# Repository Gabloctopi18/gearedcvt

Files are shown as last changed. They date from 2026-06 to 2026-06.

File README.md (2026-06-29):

# Geared, Bi-directional CVT
A continously variable transmission that is fully geared and is bi-directional. I was heavily inspired by RatioZero.
Here is the link to the CAD: [https://cad.onshape.com/documents/c369754a085e1b437744081a/w/8784f23027b47ba880d55ef1/e/7f96dc46c879863ea30c1be9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](url)

Here is my project on stardance: [https://stardance.hackclub.com/projects/4431](url)



## Context
### What is a CVT? Why CVT?
A CVT (continously variable transmission) is a gearbox which allows an infinite, continuous range of gear ratios. Unlike normal gearboxes or gear switchers, which have fixed gear ratios and sharp switching between them, a CVT allows any gear ratio between it's mechanical limits (dependent on the mechanical design). For automotive industries, CVTs are used to keep engines at optimal efficiency RPM (deviations greatly reduce efficiency) and instead change speed by varying the gear ratio. However, my CVT is meant to be used in robotics: instead of compromising between speed and torque, a CVT allows both torque and speed modes in one gearbox. Robots that are used in a wide range of scenarios and load conditions benefit from it: it can choose the optimal gear ratio for each desired action.
### Why geared? Why bi-directional?
I chose to design a geared CVT mainly becaues I thought it looked really cool. Theoretically, geared CVTs are more efficient than typical belted CVTs because gears are inherently more efficient than belts. Furthermore, belted CVTs rely solely on friction, while geared CVTs rely on the mechanical interlocking of gears, redicuing manufacturing costs. One really good and popular Geared CVT design is the RatioZero. However, that gearbox is not bi-directional because it relies on one-way bearings: when you spin the input in reverse, the ouput doesn't spin. This also implies that there is no inherent braking mechanism. In many robotics applications, it is not feasible to use another actuator as a brake, and it is often necessary for the gearbox to be able to spin in both ways (think of a robotic arm or a mecanum drivetrain for example). My CVT is fully geared and bi-directional.

## How it works

Here is a brief overview of how the whole thing works. I recommend taking a look at the CAD because it's hard to explain stuff with only images.

### Rotation Splitting
The key idea for the geared CVT is rotation splitting. The blue gear is the input gear, belted to an actuator (the belt or pulley isn't shown in the picture). Note that the input coaxial but NOT attached to the hex shaft in the center. The input gear meshes with the two gray gears. Attatched to the gray gears is an arm, which slides up and down in the slot of the gray gear. The other end is attached to another shaft. The sliding up and down is resposible for the gear shifting. When the arm is close the the center of the gray gear, the radius is small, which lowers the speed during one full rotation (the speed is $2\pi r\omega$, $\omega$ is fixed). As a result, the output torque is magnified (think of it like a seesaw, where the driven end is much shorter than the driving end). The opposite happens when the arms moves further from the center of the gray gear; the speed is increased and the torque decreases. Therefore, the gear ratio is determined by the distance from the arm to the center of the gray gear. The way the distance is changed will be explained later. Interestingly, note that the arm could move to the center of the gray gear, which implies the gear ratio is 0:1 and the output is completely independent of the input.

The second stage (other end of the arm) is designed to have 95 degrees of range. You may also note that the motion is somewhat sinusoidal (not exactly because the pushing and pulling isn't symmetric, see the math folder for that). The four gray gears have their slots 90 degrees offset from eachother. The output gear is driven only during a quarter of the gray gear's period, in the middle of the wave. Therefore, the output gear is always moving in the same direction and hardly oscillates. This is why it's called rotation splitting.



### the Selector
As mentioned previously, the second stage only drives the output during a quarter of it's period. Since all four gears are offset in phase by 90 degrees, the driven gear is constantly powered. The selection of which gear to mesh is done with a perependicular cam (I couldn't find or come up with a better name for it). On the other side of the second stage from the last section are four gears which are coaxial but NOT attatched to the second stage of shafts (one for each gear). These gears have dog clutch teeth. The gears are constantly meshed to the orange gear in the center, which is live axle onto the main center shaft. Right next to it are two dog clutches, each pointing to the gears mentioned above. The dog clutch is mounted on a linear bearing which is live axle to the second stage of shafts. 

For one gray gear tube (it's mirrored on the other side) the slots are 180 degrees offset. Each of the gears on the same side is offset by 90 degrees.

The dog clutch is linked to a linear cam. The linear cam is powered by a third gear meshing with the input. The dog clutches from each side come to sandwich the cam between two bearings, which makes the dog clutches move along with the shape of the cam. The bearing sandwich from the dog clutches on each side meet at a 90 degree angle, which means the positions between those two dog clutches are 90 degrees offset from eachother. Since the thickness of the cam says the same, the two dog clutches on one side of the gearbox are 180 degrees offset from eachother. This combination means only one gear will mesh with the output gear at a time, each for a quarter of the period. This is combined with the gear shifting described in the previous section so the output gear can vary its gear ratio.

  

### the Gear Shifter
This section covers how the arm changes radius. This was a challenge because it also has to rotate on it's axis. Inside the tubes of the gray gears is a linear CAM. moving the cam causes a rider (the blue part), secured with two linear bearings mounted to dowel pins, to move up and down. The linear cam is attached to a ring outside the tube, which is sandwiched between two bearings. The bearings are attached to a lead screw nut mounted on a leadscrew. This way, the linear can can rotate about it's axis, but when the lead screw turns, it moves the linear cam, causing the gear ratio to change. Note that the cam is mirrored to the other side: this way, each of the riders are at the same position in the slot.



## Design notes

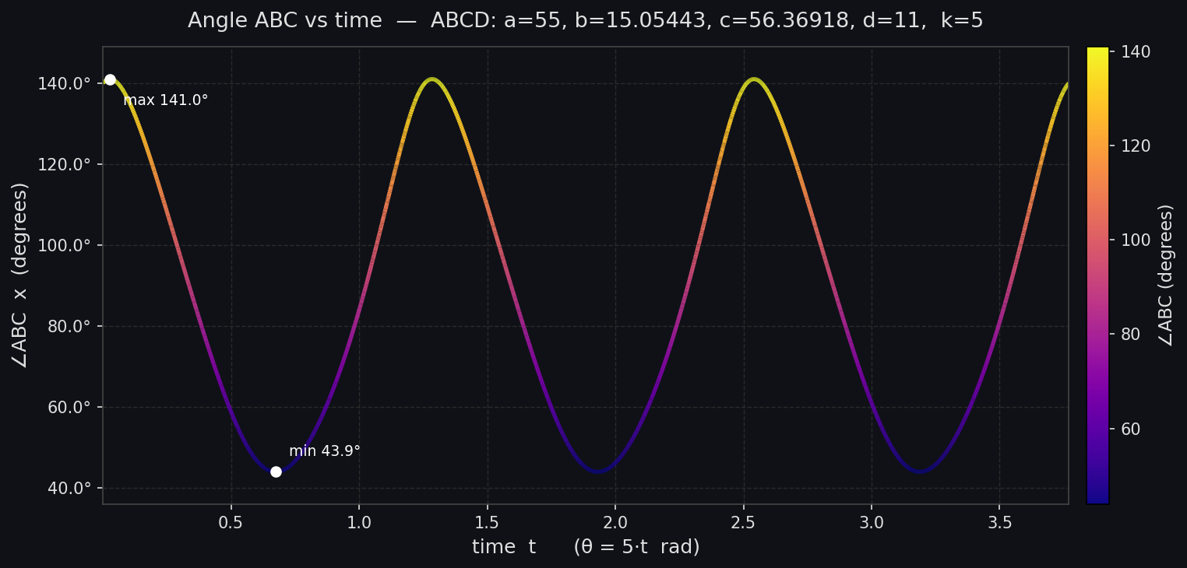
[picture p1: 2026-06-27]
math/angle_x_graph.png

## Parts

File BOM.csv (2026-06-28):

Part | QTY | Cost (per) | net cost | Link | notes
8x14mm flanged bearing hex bore | 3 | 5.99 | 17.97 | https://www.gobilda.com/1611-series-flanged-ball-bearing-8mm-rex-id-x-14mm-od-5mm-thickness-2-pack/ | packs of two
32x39mm flanged bearing | 8 | 11.99 | 95.92 | https://www.gobilda.com/32mm-id-flanged-ball-bearing-39mm-od-5mm-thickness/ | gobilda is literally the only vendor, terrible pricing
25x32mm bearing | 1 | 14.89 | 14.89 | https://www.amazon.com/uxcell-6705-2RS-Groove-Bearing-Bearings/dp/B0CNX5FZY4 | packs of 10, might asw pay 2 bucks for 10pcs
6x12mm flanged bearings | 1 | 8.99 | 8.99 | https://www.amazon.com/uxcell-6705-2RS-Groove-Bearing-Bearings/dp/B0CNX5FZY4 | packs of 10
6x12x18mm linear bearings | 1 | 7.39 | 7.39 | https://www.amazon.com/uxcell-Bearing-Bearings-Machine-Packaging/dp/B0DNSR9P8F | packs of 6
3x7x10mm linear bearings | 3 | 9.39 | 28.17 | https://www.amazon.com/PATIKIL-Bearings-Bushing-Machine-Engraving/dp/B0FQV7G4JN | packs of 4
5x10mm flanged bearings | 1 | 6.49 | 6.49 | https://www.amazon.com/PATIKIL-Bearings-Bushing-Machine-Engraving/dp/B0FQV7G4JN | packs of 4
5mm diameter lead screw 100mm L | 1 | 6.99 | 6.99 | https://www.amazon.com/ReliaBot-100mm-Tr5x2-Printer-Machine/dp/B081VN8QRM | lead screw + nut
5mm diameter lead screw nut | 1 | 4.99 | 4.99 | https://www.amazon.com/ReliaBot-100mm-Tr5x2-Printer-Machine/dp/B09S9ZH7GP | need another nut
M3 28mm dowel pin | 1 | 5.99 | 5.99 | https://www.amazon.com/ZDingTech-Support-Shelves-Rod-304-Stainless/dp/B0DZ251HCF | 50 pack
M3 60mm dowel pin | 1 | 5.79 | 5.79 | https://www.amazon.com/uxcell-Cylindrical-Mechanical-Manufacturing-Installation/dp/B0DRS9SKPJ | 10 pack
6mm OD m4 48mm standoff | 1 | 5.29 | 5.29 | https://www.gobilda.com/1501-series-m4-x-0-7mm-standoff-6mm-od-48mm-length-4-pack/ | 4 pack
6mm OD m4 32mm standoff | 1 | 4.29 | 4.29 | https://www.gobilda.com/1501-series-m4-x-0-7mm-standoff-6mm-od-32mm-length-4-pack/ | 4pack
3x6mm bearing | 1 | 8.79 | 8.79 | https://www.amazon.com/MR63ZZ-Groove-Double-Shielded-Bearings/dp/B0DY11G865 | 20pack
8mm hex shaft 64mm L | 1 | 4.69 | 4.69 | https://www.gobilda.com/8mm-rex-shaft-with-e-clip-stainless-steel-64mm-length/
8mm hex shaft 80mm L | 1 | 5.09 | 5.09 | https://www.gobilda.com/8mm-rex-shaft-with-e-clip-stainless-steel-80mm-length/
m4x4x4 heatset inserts | 1 | 5.99 | 5.99 | https://www.amazon.com/Vibit-Threaded-Soldering-Printing-Components/dp/B0G8GY9K4M | 100pack
solder | 1 | 29.99 | 29.99 | https://www.amazon.com/Soldering-Station-Digital-Display-Helping/dp/B0DJR784YW?sp_csd=d2lkZ2V0TmFtZT1zcF9hdGY | first time using it
m3 tsaras
 |  | total cost | 267.71

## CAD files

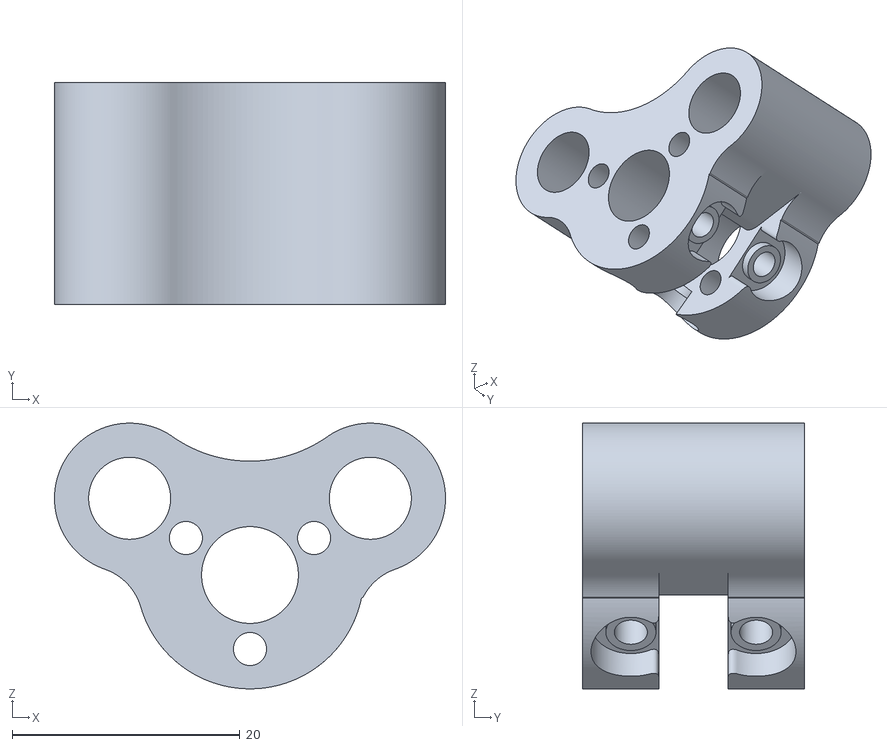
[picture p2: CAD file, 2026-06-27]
cad/3dPrint/master - Part 18.stl
34.3 x 19.5 x 23.3

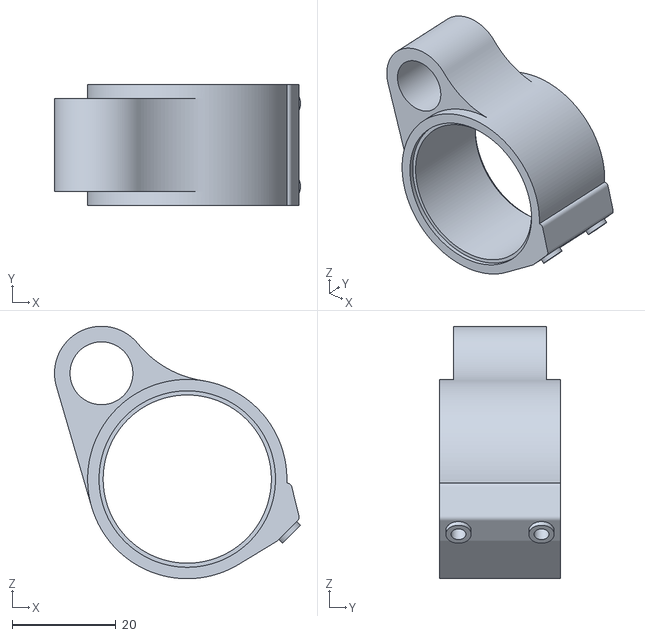
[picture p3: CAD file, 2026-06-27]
cad/3dPrint/master - Part 15.stl
47.4 x 23.4 x 48.6

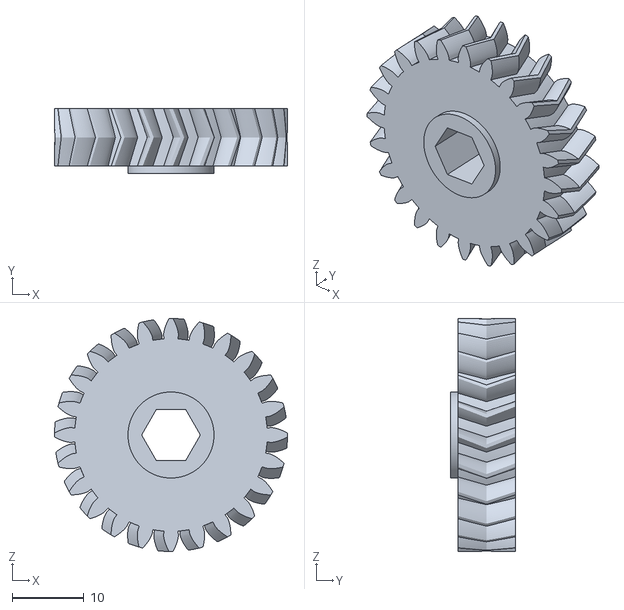
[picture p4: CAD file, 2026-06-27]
cad/3dPrint/master - ouput.stl
32.5 x 9.00 x 32.5

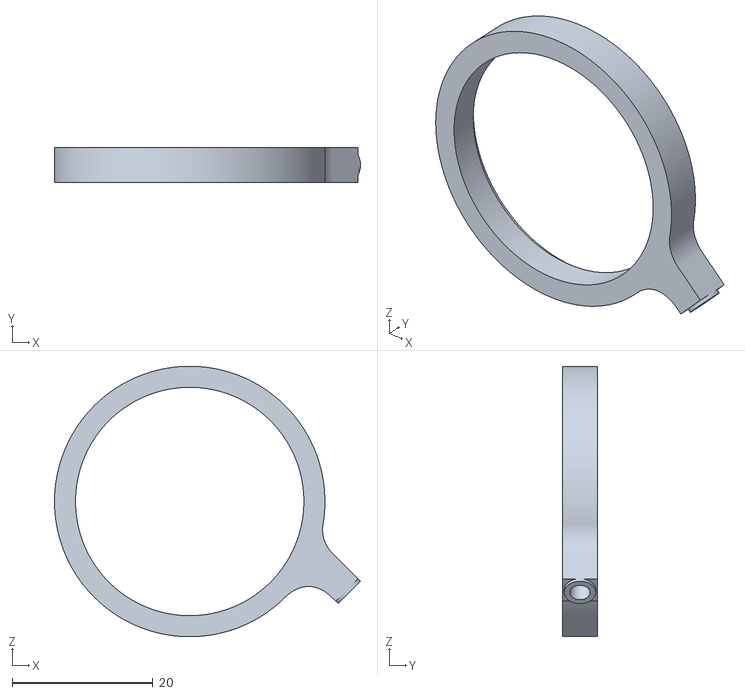
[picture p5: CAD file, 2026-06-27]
cad/3dPrint/master - Part 12.stl
43.6 x 5.00 x 38.5

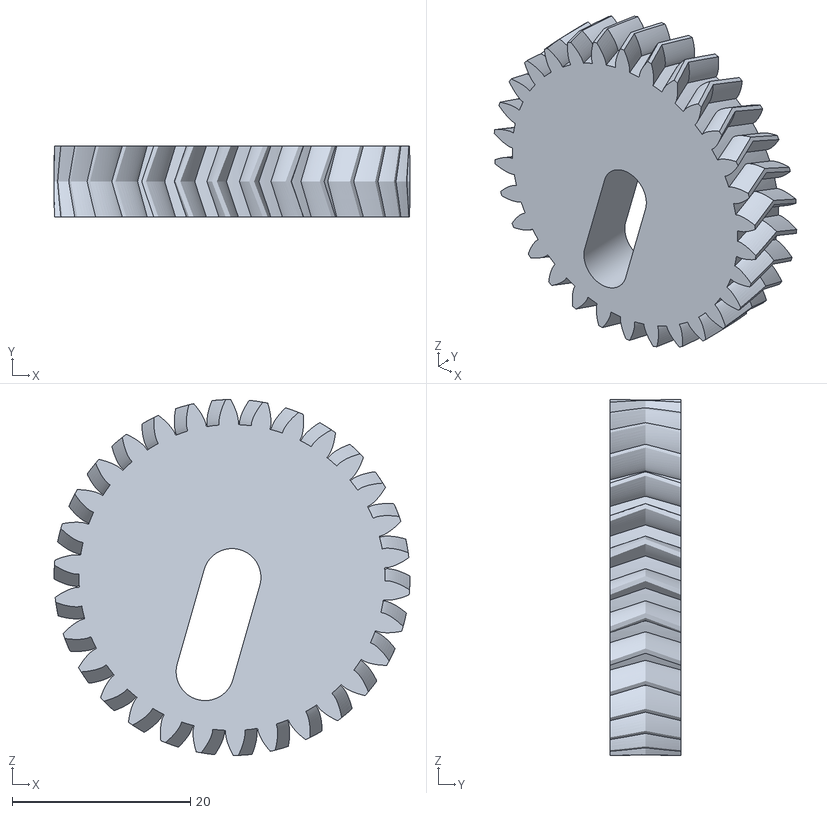
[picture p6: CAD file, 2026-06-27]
cad/3dPrint/master - USELESS.stl
40.0 x 8.00 x 40.0

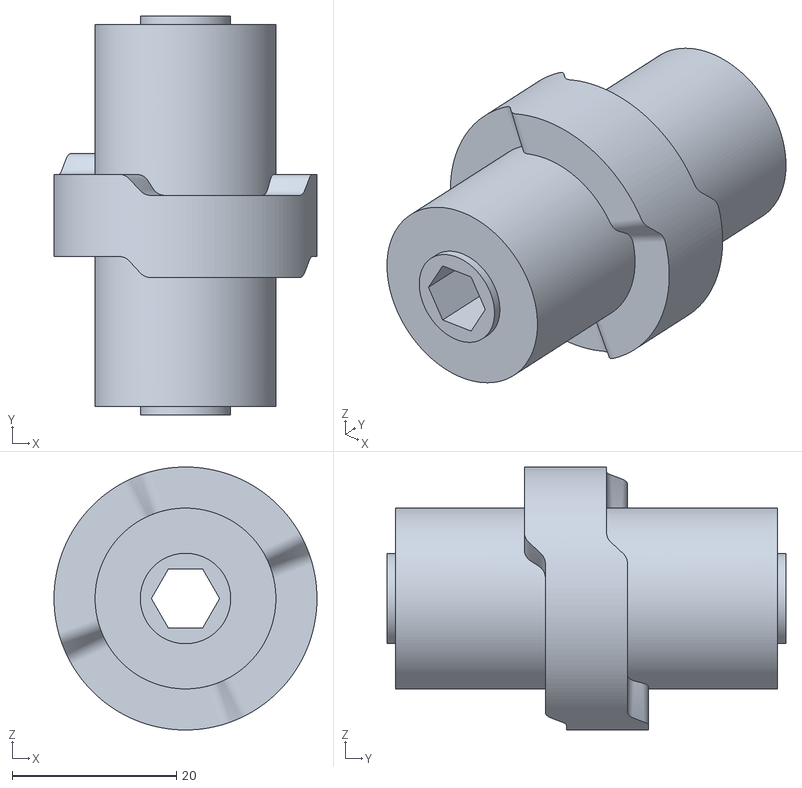
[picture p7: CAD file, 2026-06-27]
cad/3dPrint/master - Part 16.stl
32.0 x 48.5 x 32.0

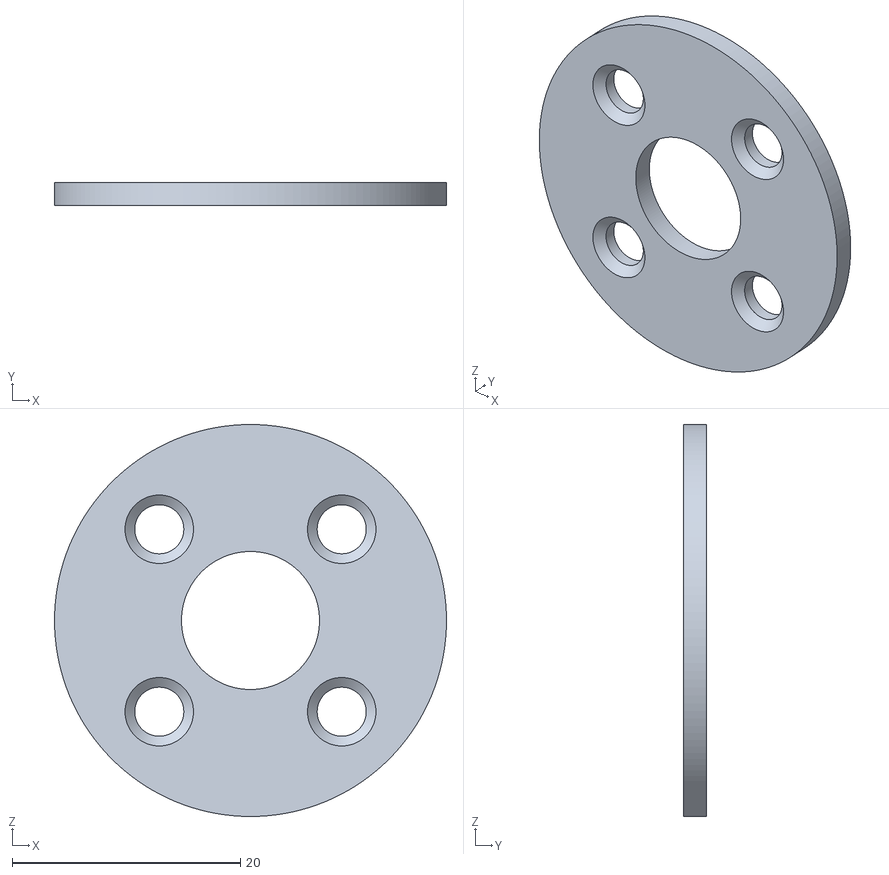
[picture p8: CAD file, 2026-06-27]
cad/3dPrint/master - Part 10.stl
34.4 x 2.00 x 34.4

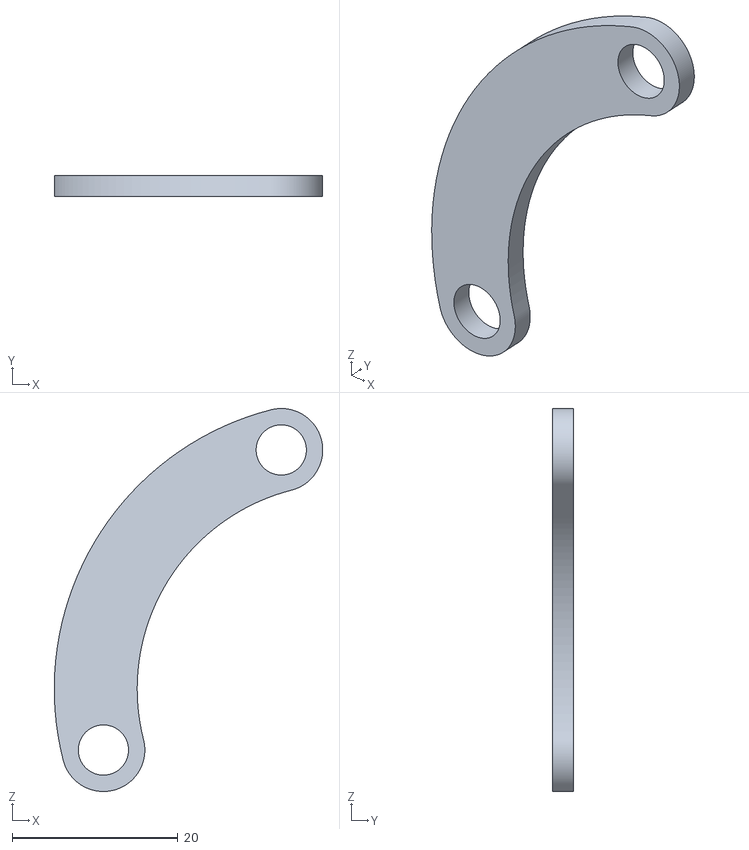
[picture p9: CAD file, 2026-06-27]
cad/3dPrint/master - Part 5.stl
32.4 x 2.50 x 46.2

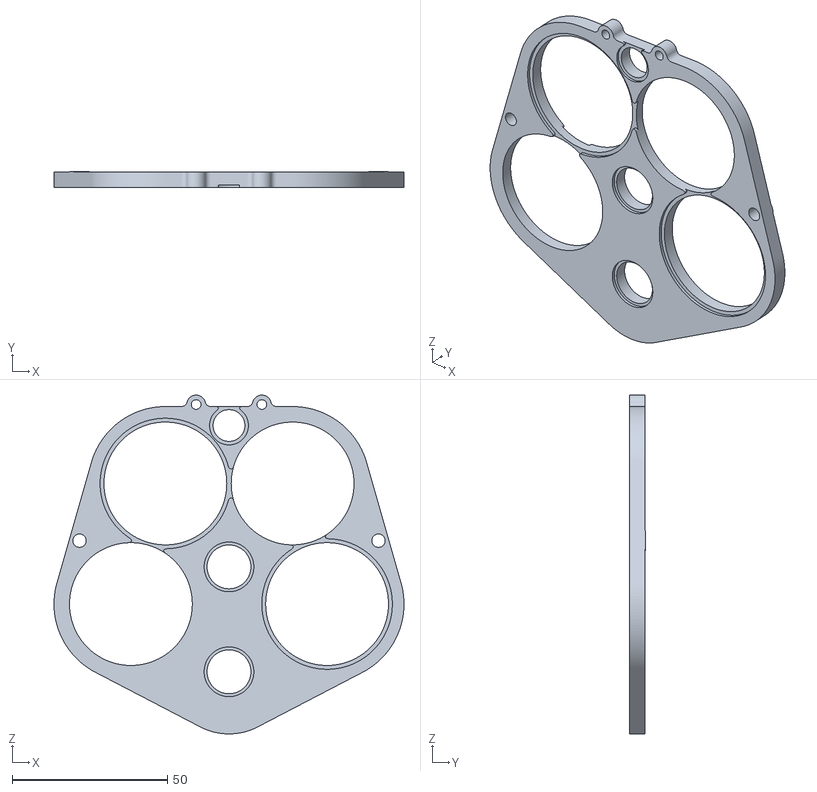
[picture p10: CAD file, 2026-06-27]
cad/3dPrint/master - Part 11.stl
112.6 x 5.26 x 109.0

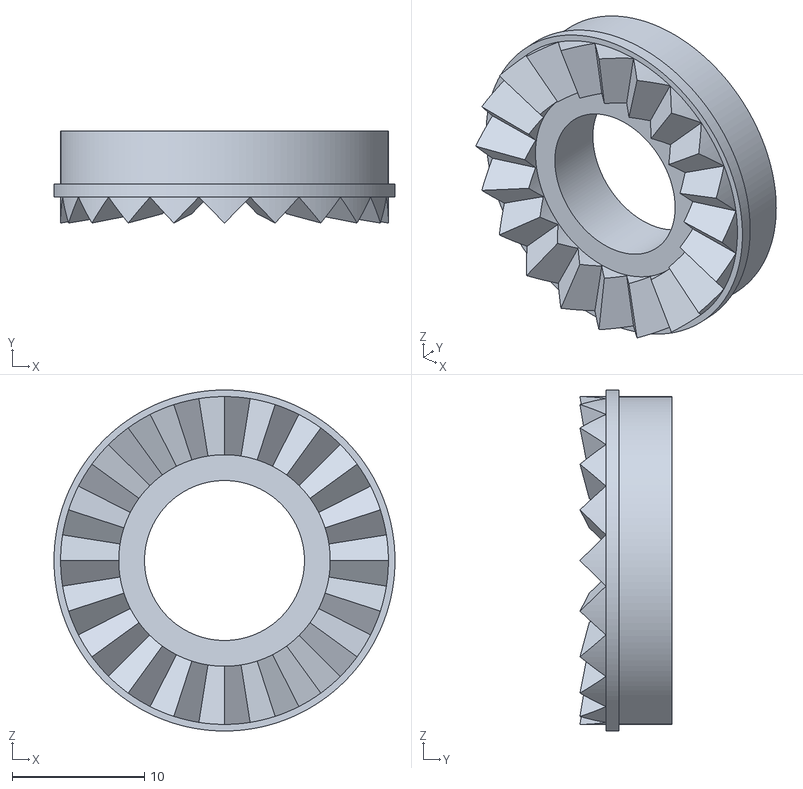
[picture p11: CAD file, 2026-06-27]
cad/3dPrint/master - Part 9.stl
25.8 x 6.96 x 25.8

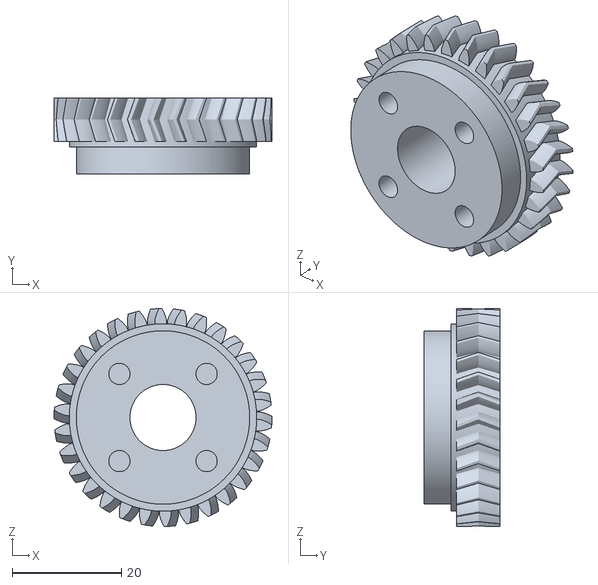
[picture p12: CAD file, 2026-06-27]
cad/3dPrint/master - dogClutchGear.stl
40.0 x 14.0 x 40.0

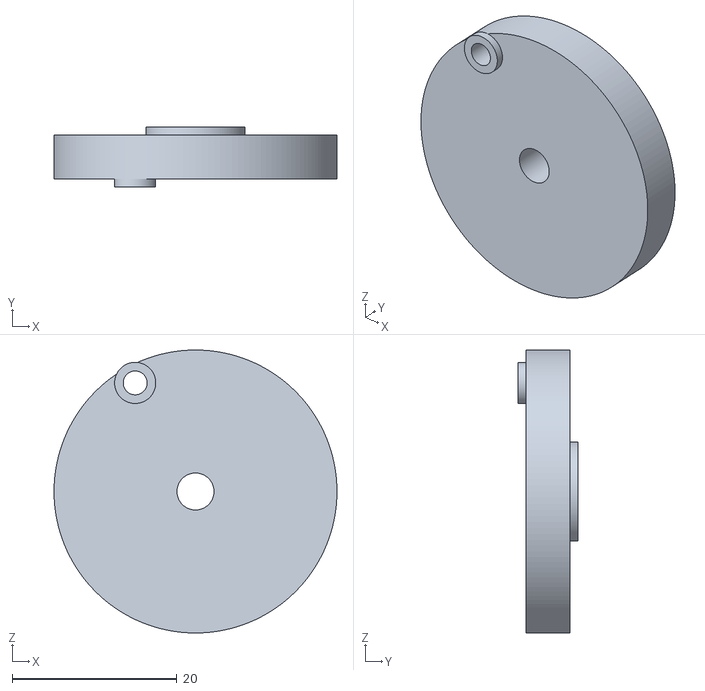
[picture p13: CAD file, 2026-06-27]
cad/3dPrint/master - Part 4.stl
34.4 x 7.30 x 34.4

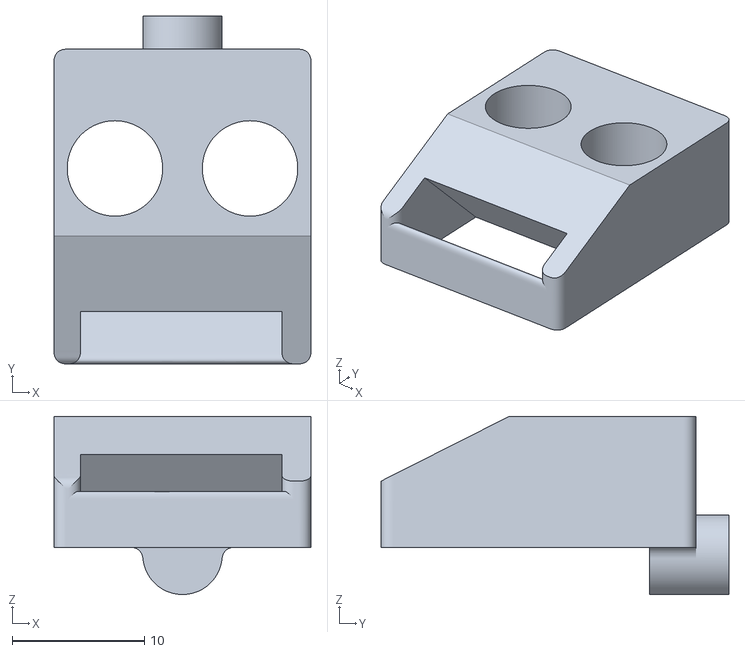
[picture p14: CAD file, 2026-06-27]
cad/3dPrint/master - Part 17.stl
19.4 x 26.3 x 13.4

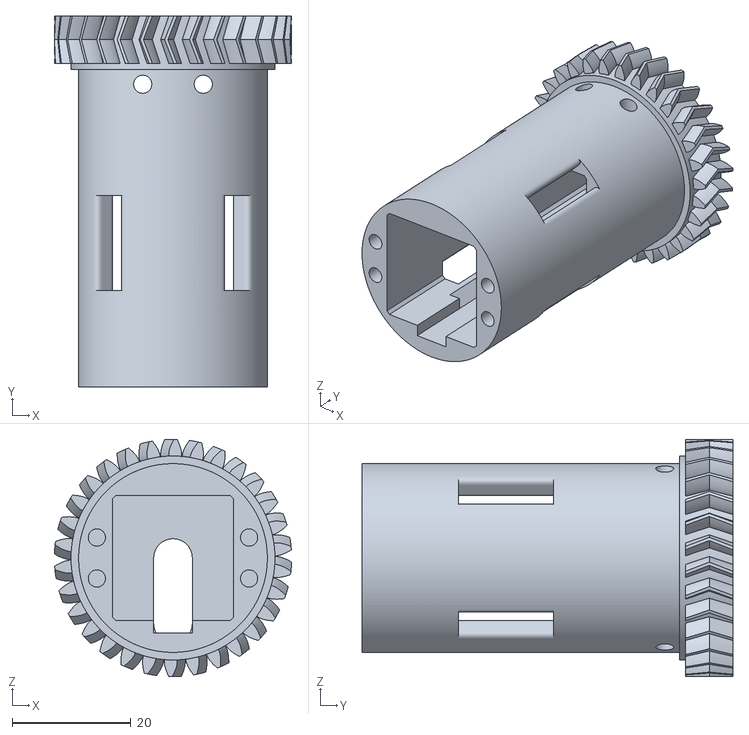
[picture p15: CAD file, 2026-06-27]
cad/3dPrint/master - 30Ttubegear.stl
40.0 x 62.5 x 40.0

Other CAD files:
cad/3dPrint/master - Part 14.stl
cad/3dPrint/master - intput.stl
cad/3dPrint/master - Part 13.stl
cad/3dPrint/master - camGear.stl
cad/3dPrint/master - 30Tgear.stl
cad/3dPrint/master - Part 8.stl
cad/COTS/25x32f.step
cad/COTS/32x39f.step
cad/COTS/3x28DowelPin.step
cad/COTS/3x6.step
cad/COTS/3x60DowelPin.step
cad/COTS/3x7lin.step
cad/COTS/5mmleadscrew.step
cad/COTS/5mmleadscrewNut.step
cad/COTS/5x10f.step
cad/COTS/6x12lin.step
cad/COTS/6x32Standoff.step
cad/COTS/6x48Standoff.step
cad/COTS/8x14hexf.step
cad/COTS/8x80RexShaft.step

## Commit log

2026-06-27 more files
    [25x32f.step, 32x39f.step, 3x28DowelPin.step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]
2026-06-28 new readme
    Added detailed explanation of the geared bi-directional CVT, including its functionality, design rationale, and how it works.
2026-06-28 update BOM
    Updated BOM.csv to include links for each part and corrected formatting.
    [BOM.csv]
